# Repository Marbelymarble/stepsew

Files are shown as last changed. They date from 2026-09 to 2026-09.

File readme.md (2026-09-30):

# Stepsew

ESP32 firmware for a pedal-controlled sewing-machine stepper motor. Releasing
the pedal after sewing stops the needle at bottom dead center (BDC). Short
pedal taps at rest toggle the needle between BDC and top dead center (TDC).

## Build

```sh
pio run -e esp32dev
```

The project pins Espressif32 7.1.3 and FastAccelStepper 1.3.0. Position capture
uses the classic ESP32's IDF 4 pulse-counter hardware; changing to another ESP32
variant or an IDF 5 platform requires adapting that code. Compiler warnings in
project sources are treated as errors.

## Wiring and configuration

Settings live in [`include/config.h`](include/config.h).

| Signal | GPIO | Configuration |
| --- | --- | --- |
| Motor STEP | 14 | Rising-edge step pulses |
| Motor DIR | 27 | Fixed LOW; forward-only operation |
| Motor ENABLE | 26 | Active LOW |
| Pedal | 2 | 12-bit analog input |
| BDC sensor | 33 | Pull-up input; falling edge marks BDC |

The defaults retain 2,000 pulses per motor revolution, 60–3,000 motor RPM, and
400,000 steps/s² acceleration. Pedal thresholds remain 2,000 for starting and
2,250 for variable speed, with 20 counts of hysteresis. Readings are sampled
every millisecond and averaged over 20 samples. The speed curve uses exponent
1.2 and is clamped to the configured speed limits.

`kStepsPerNeedleCycle` is independent of `kMotorStepsPerRevolution`. The current
value of 4,667 accounts for approximately 2.33 motor revolutions per needle
cycle with 2,000 pulses per motor revolution. Confirm the exact ratio from
pulley tooth counts or the measured BDC crossing interval. This value includes
both the pulley ratio and motor-driver microstep setting.

Align the sensor's falling edge with physical BDC. `kBdcOffsetSteps` can add a
forward offset when the sensor is mounted before BDC. The final position must
remain within the sensor's active LOW region. Homing accepts one captured
sensor pulse to plan the approach; it does not require two crossings with
matching spacing. A fresh edge is then required during the final moving
search. Both homing and the return tap use that same search.

`kBdcToTdcSteps` sets the forward distance from BDC to TDC. Its default is half
a needle cycle (2,333 steps). The return move watches for the next BDC edge
throughout its forward travel from TDC. Both moves rotate
forward. Calibrate this distance if the machine's linkage
does not put TDC exactly half a cycle after BDC. There is no TDC sensor: its
position is inferred from the established BDC reference and counted STEP pulses.

## Short pedal taps

After a successful BDC stop:

- Press and release the pedal within 20–250 ms to raise the needle to TDC.
- Once the needle has stopped at TDC, another short tap lowers it to BDC.
- Hold the pedal for 250 ms to start normal sewing. Releasing it after sewing
  homes to BDC as usual.

The motor stays still while distinguishing a tap from a held press. Tap motion
starts on pedal release. The upward move runs at 60 RPM and takes about
1.2 seconds with the default settings. The downward move scans continuously
at 60 RPM from TDC and requests normal deceleration when a falling edge is
captured. It clears pending capture and the preceding debounce lockout before
starting, and uses speed-dependent debounce throughout the return. Capture is
not restricted to an estimated half-cycle endpoint or a narrow window around it.
The return has a finite travel limit of one nominal needle cycle (4,667 steps),
so a missing signal cannot cause unlimited rotation. It normally stops at the
first usable BDC crossing, about half a cycle from TDC. Homing also allows
a full-cycle search after its approach, so a noisy planning reference cannot
restrict final capture to a narrow predicted window.

Queued pulses and braking cause some travel beyond the captured edge. The
maximum accepted travel beyond the configured BDC offset is calculated from
speed, queue planning, latency allowance, and acceleration
(`kBdcCaptureToleranceSteps`: 44 pulses, about 3.4° of the needle cycle at
60 RPM). A direct scan entered from up to 120 RPM budgets up to 97 pulses
for the initial queued speed and deceleration. This is a limit, not a commanded offset or a guarantee of exact
physical BDC. After motion ends, HIGH samples reset LOW qualification but
allow up to 50 ms (`kBdcStopQualificationMs`) for the mechanism/input to settle
before rejecting the candidate. The sensor must still stay LOW for 10 ms at
rest, followed by final verification. If the sensor's active region is too narrow for braking,
the search continues within its remaining travel budget and otherwise faults.
Align the magnet/sensor and calibrate `kBdcOffsetSteps` for the physical stop.
`BDC stop: edge_to_stop=... offset=...` reports the measured pulse travel.
The next upward move subtracts the measured overrun from its step count to
retain the configured TDC target relative to the captured BDC reference.
Tap duration is measured using the filtered pedal reading
and the existing start/release hysteresis; pulses shorter than 20 ms are ignored.
Adjust `kPedalTapMinMs` and `kPedalTapMaxMs` to change these durations.

Wait for each toggle to finish before tapping again. Short presses during a
toggle are ignored rather than queued. A held press during a toggle resumes
sewing after the same 250 ms threshold, including when the toggle finishes
during that press. A continuous hold cannot trigger repeated toggles.

The controller verifies the final pulse counts and requires a stable LOW BDC
sensor at BDC, or a stable HIGH sensor at TDC, before releasing the motor.
The upward toggle deadline is about 3.3 seconds with the current configuration
and scales with the configured needle-cycle length. Returning to BDC allows
three additional seconds for the search (`kBdcSearchTimeoutMs`). Timeout
messages distinguish motion, sensor search, and final sensor verification.
Failures latch the same fault as
homing; they do not switch the remembered needle position.

Taps are enabled only after a verified BDC stop. At power-up, a pedal press
starts sewing immediately as before; sew and release once to establish the
reference. A detected sensor crossing or changed level while parked invalidates
the reference. After manually moving the handwheel, sew and release again
before using taps: the single BDC sensor cannot detect every manual movement,
particularly near TDC.

## Stop behavior

1. Pedal release starts homing once, from either sewing-speed mode.
2. At or below `kPositionFeedbackMaxRpm` (120 motor RPM by default), release
   converts the existing motion directly into a finite scan at 60 RPM, watching
   for the next Hall edge immediately. Actual, queued, and requested speed
   must all be within the threshold. It logs `Homing: direct low-speed BDC scan`.
   This path has no predicted approach point and requires no earlier reference
   or qualifying stitch. A recent edge still under the sensor can request an
   immediate stop. Travel remains limited to one nominal cycle, and normal
   braking and final LOW verification still apply. An edge already passed
   outside the usable stop region cannot be recovered by reversing.
3. Above the low-speed threshold, the motor changes to 120 RPM
   (4,000 STEP pulses/s). The controller waits
   until current and queued speeds are low enough for 50 ms before planning
   the stop. `kHomingRpm` controls this speed independently of sewing and taps.
4. BDC pulses are tracked during sewing and deceleration for diagnostics.
   Once speed has settled, pending capture and the previous reference are
   discarded. One fresh falling edge at homing speed establishes the reference
   for the approach; no reference from high-speed motion is reused.
5. The motor moves forward to a reachable approach position 93 steps before
   the estimated BDC edge, adding complete needle cycles when required by
   queued pulses and braking distance (`kBdcApproachLeadSteps`). The estimate is
   only an approach target; the final scan allows a full nominal cycle.
   At the current ratio, one needle cycle at homing speed takes about 1.17 s.
6. `Homing: locating the BDC sensor edge` starts the same bounded, continuous
   60 RPM search used by the return tap. A fresh edge with a stable LOW at rest is
   required. An earlier sewing pulse alone cannot establish the final stop.
7. After applying any BDC offset, the controller verifies both the library's
   position and the independent hardware pulse count and requires the sensor
   to remain LOW for 10 ms before releasing the motor outputs.

A pedal press lasting at least 50 ms (`kHomingResumePressMs`) cancels homing
and resumes sewing. Release hysteresis resets that timer; a brief pedal rebound
cannot cancel the stop. The next release either starts a direct low-speed scan
or reacquires a reference at settled speed. A new sewing
session from rest starts fresh reference acquisition, so references from before
a handwheel adjustment are not reused. The controller does not automatically
move or assume it is homed at power-up.

The sensor interrupt applies a speed-dependent falling-edge lockout:

`lockout_us = 1,000,000 × steps_per_needle_cycle / pulses_per_second × 50%`

`kSensorDebouncePercent` controls that fraction. At steady speed the defaults
are about 1,167 ms at 60 motor RPM, 583 ms at 120 RPM, and 23 ms at 3,000 RPM.
The rate uses the highest actual, queued, or requested pulse frequency, so
acceleration shortens the lockout promptly. An active lockout uses the smaller
of its original duration and the current duration: deceleration cannot extend
it and hide the next crossing. Rejected edges do not restart the timer.
Calculations run in the control loop; the ISR uses the published duration and
retains the first edge's timestamp and pulse count.

The moving lockout is bounded by `kSensorDebounceMinUs` (1 ms) and
`kSensorDebounceMaxUs` (2 s). At rest the setting is
`kSensorStoppedDebounceUs` (500 ms). The final BDC search uses the same
speed-dependent debounce as sewing: there is no search-specific 1 ms override.
Candidate rejection does not reset debounce, so repeated edges from the same
burst cannot repeatedly restart braking. A false first edge can still mask a
nearby genuine edge during its lockout; the finite travel and time limits
remain in effect.

This suppresses repeated edges but cannot distinguish an isolated noise spike
from a genuine Hall crossing. No minimum pulse width is required. The handler
does not reread the input level to decide whether an edge counts:
a pulse may already have ended when the interrupt or control loop runs. The
first pending edge's timestamp and hardware pulse count are retained until the
loop consumes them, so bounce cannot replace that reference. Subsequent edges
within three quarters of a needle cycle are ignored based on motor travel.
No exact two-pulse spacing check is used. The final scan searches up to one
nominal cycle from the approach and faults if no usable edge is found. Large raw interrupt counts can indicate
chatter or interference; software cannot establish physical BDC from a signal
that also stays active at unrelated positions.

PCNT unit 7 independently counts STEP pulses, including while the application
is busy. The sensor interrupt captures that count without resetting the
library's position. Unsigned position differences handle counter wraparound.
Units used internally by FastAccelStepper are left available to the library.

`kForwardPlanningMs` is 8 ms, configured only during motor initialization.
FastAccelStepper's task refills roughly every 4 ms; this retains two refill
cycles while reducing queued travel before a normal stop can take effect.
At 60 RPM, 8 ms corresponds to 16 pulses, versus 40 pulses with the former
20 ms setting. Task timing and deceleration add further travel, so this is
neither an exact stop distance nor a guarantee that the magnet remains in the
sensor's active region. Both sewing and positioning use this queue setting;
check smooth high-speed operation as well as the final stop after changing it.

The homing deadline covers two needle cycles at homing speed, maximum
deceleration, settling, a one-second margin, and three seconds for the final
edge search (about 6.6 seconds total with the current settings). Missing or unusable sensor
signals, failed motor commands, and position mismatches latch a fault. The
motor decelerates and its outputs are released once it stops. If a fault stop
has not completed within one second, pending pulses are aborted. Correct the
cause and reset the controller to resume; pressing the pedal cannot clear a
fault. Serial output at 115200 baud reports state transitions and fault causes.

Homing timeout messages identify the stage that failed. They also report the
sensor level, raw falling-edge interrupts, `debounced` edges rejected by the
time lockout, captured/stale/ignored edges,
accepted references, last observed interval, last accepted interval, and
hardware pulse count. The last observed interval may describe rejected bounce;
the accepted interval shows spacing between references used for planning. Counts
cover the current sewing session, including deceleration and reference
acquisition. `raw=0` means no falling-edge interrupts reached the handler;
`raw` can exceed `captured` due to debounce and when multiple admitted edges
arrive before the loop consumes the first one. The interval is diagnostic only, not an exact-spacing
requirement. The 16-bit hardware pulse count wraps every 65,536 steps, while
the library position continues counting; only their low 16 bits must match.
Diagnostics are printed after requesting a stop, so they do not delay capture.

A live `BDC pin=33 HIGH raw=... db=... read=... merged=... us=...` status line
is attempted once per second, including while stopped or faulted. It skips
printing if the serial transmit buffer lacks room. These counters start at boot:

- `raw`: all falling-edge interrupts, before debounce.
- `db`: interrupts rejected by the time lockout.
- `read`: captured events consumed by the control loop, before position filtering.
- `merged`: admitted interrupts coalesced while an earlier event was pending.
- `us`: currently configured lockout in microseconds; an existing lockout may
  be shorter because it began at a faster speed.

The HIGH/LOW value is an instantaneous reading and may miss a short pulse;
the raw counter retains evidence of its interrupt. Moving the magnet past the
sensor by hand while stopped can therefore check capture independently of motor
operation. Search faults also print `observed`, `stale`, `outside`, and
`returned_HIGH` counts. The latter identifies captured candidates rejected
because LOW did not persist at rest. `BDC rejected edges` additionally reports
minimum and maximum pulse travel from those edges to standstill, to help
distinguish signal glitches from braking past the active region. These counts
alone do not prove which cause applies. `outside` includes approach edges before
the final search window, which are normally ignored.

## Hardware verification

A successful build cannot establish mechanical positioning accuracy. Before
using the positioning feature:

- Confirm the driver microstep setting, pulses per needle cycle, rotation
  direction, and the sensor's falling-edge alignment with needle-down BDC.
- Release the pedal from minimum and higher speeds at several points in the
  needle cycle. Confirm the needle consistently finishes at BDC, motion has
  ended before ENABLE is released, and the serial output reaches `Stopped`.
- Press the pedal again while slowing, seeking BDC, and approaching the target.
  Confirm sewing resumes without reversing or briefly disabling the driver.
- After a verified BDC stop, tap once and check physical TDC, then tap again
  and check BDC. The return should report `Tap: locating the BDC sensor edge`
  before `Stopped: needle at BDC`. Confirm each tap produces just one toggle,
  all motion is forward, and the needle stays at its final position after the
  driver is released. Repeat the sequence to check that BDC does not drift.
- Hold the pedal at BDC and TDC. Confirm normal sewing starts after 250 ms and
  releasing the pedal returns to BDC. Check a held press during a toggle too.
- With the mechanism unloaded, check a disconnected sensor and a sensor held
  LOW. Homing must time out, stop the motor, and reject pedal input until reset.
- Check repeated stops and restarting after manually turning the handwheel.
  Release at different points during minimum-speed sewing and check for the
  direct-scan message, without `Homing: approaching BDC`. Release after fast sewing and check for fresh reference
  acquisition after speed settling. If BDC verification fails, check
  the sensor's active region and calibration rather than increasing the timeout.

No software tests are included.

## Source layout

- `main.cpp`: Arduino setup and control-loop scheduling.
- `machine.cpp`: sewing, tap gestures, BDC/TDC positioning, and fault states.
- `stepper.cpp`: FastAccelStepper commands and pulse-based stop planning.
- `bdc_sensor.cpp`: interrupt capture and atomic event transfer.
- `pedal.cpp`: fixed-size averaging and bounded speed mapping.

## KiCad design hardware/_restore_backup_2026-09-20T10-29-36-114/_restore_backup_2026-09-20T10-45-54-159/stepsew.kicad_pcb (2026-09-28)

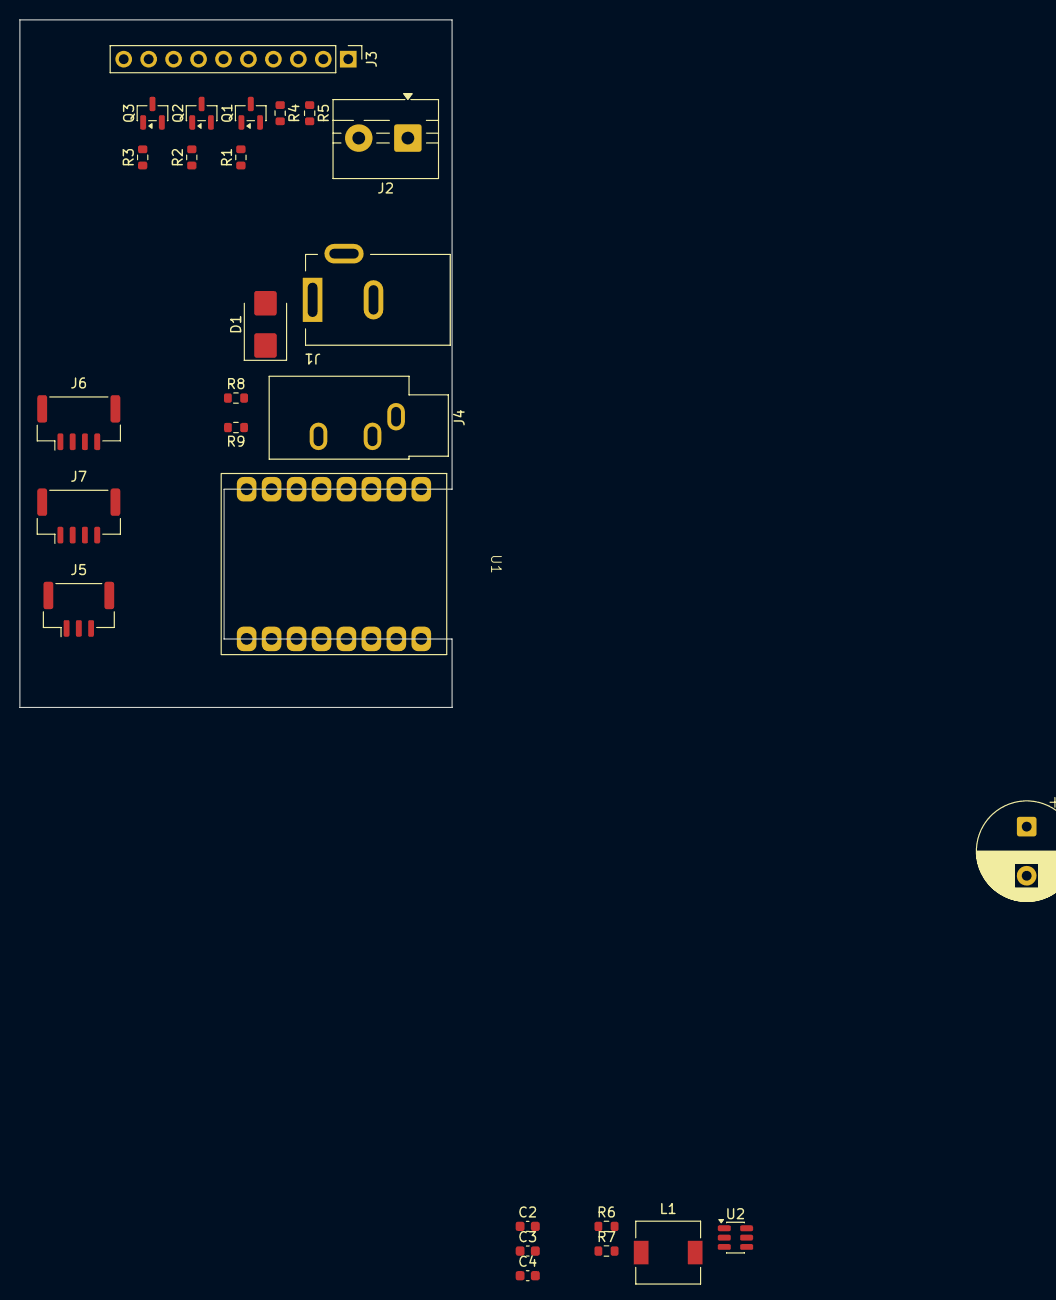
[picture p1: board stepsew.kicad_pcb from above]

Board: 2 copper layers, 44.0 x 70.0 mm, 27 parts (0 on the bottom side), 27 nets, no tracks yet.

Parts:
C1: 330uF 63V; CP_Radial_D10.0mm_P5.00mm
C2: 2u2; C_0603_1608Metric
C3: 100n; C_0603_1608Metric
C4: 10u; C_0603_1608Metric
D1: D_TVS; D_SMB
J1: Barrel_Jack_MountingPin; BarrelJack_Kycon_KLDX-0202-xC_Horizontal
J2: Servo Power; TerminalBlock_MaiXu_MX126-5.0-02P_1x02_P5.00mm
J3: Servo Header; PinHeader_1x10_P2.54mm_Vertical
J4: Pedal; Jack_3.5mm_CUI_SJ1-3533NG_Horizontal
J5: HallSensor; JST_GH_BM03B-GHS-TBT_1x03-1MP_P1.25mm_Vertical
J6: OLED; JST_GH_BM04B-GHS-TBT_1x04-1MP_P1.25mm_Vertical
J7: Encoder; JST_GH_BM04B-GHS-TBT_1x04-1MP_P1.25mm_Vertical
L1: 15uH; L_6.3x6.3_H3
Q1, Q2, Q3: BC817; SOT-23
R1, R2, R3: 220R; R_0603_1608Metric
R4, R5: 10k; R_0603_1608Metric
R6: 118k; R_0603_1608Metric
R7: 22k1; R_0603_1608Metric
R8: 1k; R_0603_1608Metric
R9: 6k8; R_0603_1608Metric
U1: ESP32-C3-SuperMini
U2: LMR54406; SOT-23-6

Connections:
+3V3: J6.1, R4.2, R5.2, R8.1
+5V: C4.1, J3.6, J3.8, J3.10, J5.1, L1.2, R6.1
+36V: C1.1, C2.1, D1.2 (A2), J1.1, J2.1, U2.4 (~SHDN), U2.5 (VIN)
/Enc_A: J7.1, U1.4 (GPIO4)
/Enc_B: J7.2, U1.3 (GPIO3)
/Enc_SW: J7.3, U1.2 (GPIO2)
/PEDAL: J4.S, R8.2, U1.0 (GPIO0)
/SCL: J6.3, U1.7 (GPIO7)
/SDA: J6.4, U1.6 (GPIO6)
/Sensor: J5.2, U1.1 (GPIO1)
/~ALM: J3.1, R3.1, U1.10 (GPIO10), U1.20 (GPIO20)
/~DIR: R2.1, U1.9 (GPIO9)
/~ENA: R1.1, U1.8 (GPIO8)
/~PED: J3.3, U1.21 (GPIO21)
GND: C1.2, C2.2, C4.2, D1.1 (A1), J1.2, J2.2, J5.3, J6.2, J7.4, Q1.2 (E), Q2.2 (E), Q3.2 (E), R7.2, R9.2, U2.2 (GND)
unnamed: J3.2, R5.1
unnamed: J3.4, R4.1
unnamed: J3.5, Q1.3 (C)
unnamed: J3.7, Q2.3 (C)
unnamed: J3.9, Q3.3 (C)
unnamed: J4.T, R9.1
unnamed: Q1.1 (B), R1.2
unnamed: Q2.1 (B), R2.2
unnamed: Q3.1 (B), R3.2
unnamed: C3.1, U2.1 (CB)
unnamed: R6.2, R7.1, U2.3 (FB)
unnamed: C3.2, L1.1, U2.6 (SW)

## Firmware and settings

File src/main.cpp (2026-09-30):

#include <Arduino.h>

#include "config.h"
#include "bdc_sensor.h"
#include "machine.h"
#include "pedal.h"

namespace {

uint32_t lastSampleMs = 0;

}  // namespace

void setup() {
  Serial.begin(Config::kSerialBaud);
  Pedal::begin();
  Machine::begin();
  lastSampleMs = millis() - Config::kControlPeriodMs;
}

void loop() {
  const uint32_t now = millis();
  if (static_cast<uint32_t>(now - lastSampleMs) < Config::kControlPeriodMs) {
    return;
  }
  // Do not insert back-to-back samples to catch up after a delayed iteration.
  lastSampleMs = now;
  Machine::update(Pedal::sample(), now);
  BdcSensor::reportDiagnostics(now);
}

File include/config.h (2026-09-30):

#pragma once

#include <stddef.h>
#include <stdint.h>

namespace Config {

constexpr uint8_t kStepPin = 14;
constexpr uint8_t kDirectionPin = 27;
constexpr uint8_t kEnablePin = 26;  // Active low.
constexpr uint8_t kPedalPin = 2;
constexpr uint8_t kBdcPin = 33;  // Active low; falling edge marks BDC.

constexpr uint32_t kSerialBaud = 115200;
constexpr uint32_t kControlPeriodMs = 1;
constexpr size_t kPedalSamples = 20;
constexpr int kPedalEnableThreshold = 2000;
constexpr int kPedalHysteresis = 20;
constexpr int kPedalVariableThreshold = 2250;
constexpr int kPedalMax = 4095;
constexpr float kPedalExponent = 1.2f;
constexpr uint32_t kPedalTapMinMs = 20;
constexpr uint32_t kPedalTapMaxMs = 250;
// Reject brief pedal rebound while homing, without imposing the tap hold delay.
constexpr uint32_t kHomingResumePressMs = 50;

constexpr uint32_t kMotorStepsPerRevolution = 2000;
// Approximately 2.33 motor revolutions per needle cycle (about 7:3).
// Confirm this rounded value against the sensor's measured crossing interval.
constexpr uint32_t kStepsPerNeedleCycle = 4667;
// Forward distance from physical BDC to TDC; adjust for the machine's linkage.
constexpr uint32_t kBdcToTdcSteps = kStepsPerNeedleCycle / 2;
// Calibrate the sensor's falling edge at BDC. A positive offset stops this many
// steps beyond that edge and must remain inside the sensor's active region.
constexpr uint32_t kBdcOffsetSteps = 0;
// Approach the expected BDC edge early, then scan at the needle-toggle speed.
// Stop 2% of a nominal cycle early; the final scan can cover a full cycle.
constexpr uint32_t kBdcApproachLeadSteps = kStepsPerNeedleCycle / 50;
constexpr uint32_t kBdcSearchTimeoutMs = 3000;
constexpr uint32_t kMinRpm = 60;
constexpr uint32_t kMaxRpm = 3000;
constexpr int32_t kAccelerationStepsPerSecondSquared = 400000;
constexpr uint32_t kHomingRpm = 150;
// At/below this actual, queued, and requested rate, scan directly on release.
constexpr uint32_t kPositionFeedbackMaxRpm = 150;
constexpr uint32_t kPositionFeedbackMaxHz =
    kPositionFeedbackMaxRpm * kMotorStepsPerRevolution / 60;
constexpr uint32_t kHomingHz = kHomingRpm * kMotorStepsPerRevolution / 60;
constexpr uint32_t kNeedleMoveHz = kMinRpm * kMotorStepsPerRevolution / 60;
// Allow a full needle cycle plus time for acceleration and final verification.
constexpr uint32_t kNeedleMoveTimeoutMs =
    1000 + (UINT64_C(1000) * kStepsPerNeedleCycle + kNeedleMoveHz - 1) / kNeedleMoveHz;

// PCNT 6 and 7 are free on the classic ESP32 with FastAccelStepper's IDF 4 driver.
constexpr uint8_t kPositionCounterUnit = 7;
constexpr uint32_t kSensorEventMaxAgeUs = 50000;
// Edge lockout, not a minimum LOW duration: short Hall pulses still count.
constexpr uint32_t kSensorDebouncePercent = 50;
constexpr uint32_t kSensorDebounceMinUs = 1000;
constexpr uint32_t kSensorDebounceMaxUs = 2000000;
constexpr uint32_t kSensorStoppedDebounceUs = 500000;
// Reject additional crossings within the same revolution, without demanding
// an exact interval from an approximate pulley ratio.
constexpr uint32_t kSensorMinSeparationSteps = kStepsPerNeedleCycle * 3 / 4;
constexpr uint32_t kReferenceMaxTravelSteps = kStepsPerNeedleCycle * 5 / 4;
constexpr uint32_t kHomingSpeedSettleMs = 50;
constexpr uint32_t kStopSettleMs = 10;
// Give the mechanism/input time to settle after STEP pulses end. During this
// window HIGH resets LOW qualification instead of immediately rejecting BDC.
constexpr uint32_t kBdcStopQualificationMs = 50;
constexpr uint32_t kFaultStopTimeoutMs = 1000;
// FastAccelStepper refills about every 4 ms. Two cycles of lookahead reduce
// sensor-to-stop latency while retaining a refill margin. Set only at startup.
constexpr uint32_t kForwardPlanningMs = 8;
// Bound capture-to-stop travel: queued motion, control/engine latency, braking.
// The final Hall LOW check remains mandatory even within this pulse budget.
constexpr uint32_t bdcCaptureToleranceSteps(uint32_t speedHz) {
  return (speedHz * (kForwardPlanningMs + kControlPeriodMs + 10) + 999) / 1000 +
         (UINT64_C(1) * speedHz * speedHz + 2 * kAccelerationStepsPerSecondSquared - 1) /
             (2 * kAccelerationStepsPerSecondSquared) + 1;
}
constexpr uint32_t kBdcCaptureToleranceSteps = bdcCaptureToleranceSteps(kNeedleMoveHz);
constexpr uint32_t kPlanningMarginSteps = kHomingHz / 20;  // 50 ms at homing speed.
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

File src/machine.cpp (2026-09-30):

#include "machine.h"

#include <Arduino.h>

#include "bdc_sensor.h"
#include "config.h"
#include "pedal.h"
#include "stepper.h"

namespace {

enum class State {
  Stopped,
  MinimumSpeed,
  VariableSpeed,
  Slowing,
  SeekingBdc,
  Positioning,
  HomingBdcSearch,
  HomingBdcOffset,
  Settling,
  MovingNeedle,
  SeekingNeedleBdc,
  SettlingNeedle,
  Fault
};

enum class NeedlePosition { Unknown, Bottom, Top };

State state = State::Stopped;
NeedlePosition needlePosition = NeedlePosition::Unknown;
NeedlePosition needleDestination = NeedlePosition::Unknown;
uint32_t homingStartedMs = 0;
uint32_t slowSinceMs = 0;
uint32_t settledSinceMs = 0;
uint32_t faultStartedMs = 0;
uint32_t referencePosition = 0;
uint32_t targetPosition = 0;
uint32_t needleMoveStartedMs = 0;
uint32_t bdcParkOverrunSteps = 0;
uint32_t bdcSearchStart = 0;
uint32_t bdcSearchRemaining = 0;
uint32_t bdcSearchLimit = 0;
uint32_t bdcEdgePosition = 0;
uint32_t bdcCaptureTolerance = Config::kBdcCaptureToleranceSteps;
bool bdcAcceptEntryEdge = false;
bool bdcSearchStarted = false;
bool bdcSearchStopping = false;
bool bdcStopObserved = false;
uint32_t bdcStoppedSinceMs = 0;
bool haveBdcEdge = false;
bool bdcCandidateLow = false;
uint32_t bdcCandidateLowSinceMs = 0;
uint32_t pedalPressedMs = 0;
bool slowSpeedReached = false;
bool haveReference = false;
bool sensorSettled = false;
bool pedalDown = false;
bool tapEligible = false;
bool delayStartForTap = false;

struct ReferenceDiagnostics {
  uint32_t rawEdgeStart = 0;
  uint32_t debounceRejectedStart = 0;
  uint32_t edges = 0;
  uint32_t staleEdges = 0;
  uint32_t ignoredEdges = 0;
  uint32_t acceptedEdges = 0;
  uint32_t lastIntervalSteps = 0;
  uint32_t lastAcceptedIntervalSteps = 0;
};

ReferenceDiagnostics referenceDiagnostics;

struct SearchDiagnostics {
  uint32_t observed = 0;
  uint32_t stale = 0;
  uint32_t outsideWindow = 0;
  uint32_t returnedHigh = 0;
  uint32_t minRejectedTravel = UINT32_MAX;
  uint32_t maxRejectedTravel = 0;
};

SearchDiagnostics searchDiagnostics;

const char* stateName(State value) {
  switch (value) {
    case State::Stopped:
      if (needlePosition == NeedlePosition::Bottom) {
        return "Stopped: needle at BDC";
      }
      if (needlePosition == NeedlePosition::Top) {
        return "Stopped: needle at TDC";
      }
      return "Stopped";
    case State::MinimumSpeed: return "Sewing: minimum speed";
    case State::VariableSpeed: return "Sewing: pedal speed";
    case State::Slowing: return "Homing: settling at homing speed";
    case State::SeekingBdc: return "Homing: acquiring BDC reference";
    case State::Positioning: return "Homing: approaching BDC";
    case State::HomingBdcSearch: return "Homing: locating the BDC sensor edge";
    case State::HomingBdcOffset: return "Homing: applying BDC offset";
    case State::Settling: return "Homing: checking final position";
    case State::MovingNeedle: return "Tap: moving needle to the opposite position";
    case State::SeekingNeedleBdc: return "Tap: locating the BDC sensor edge";
    case State::SettlingNeedle: return "Tap: checking final position";
    case State::Fault: return "FAULT: reset controller to resume";
  }
  return "Unknown state";
}

void changeState(State next) {
  if (state != next) {
    state = next;
    Serial.println(stateName(state));
  }
}

void fault(const char* reason, uint32_t nowMs) {
  const bool wasSearching = state == State::HomingBdcSearch || state == State::SeekingNeedleBdc;
  needlePosition = NeedlePosition::Unknown;
  tapEligible = false;
  haveReference = false;
  Motor::requestStop();
  faultStartedMs = nowMs;
  changeState(State::Fault);
  Serial.println(reason);
  if (wasSearching) {
    Serial.printf("BDC search edges: observed=%lu stale=%lu outside=%lu returned_HIGH=%lu latched=%s\n",
                  static_cast<unsigned long>(searchDiagnostics.observed),
                  static_cast<unsigned long>(searchDiagnostics.stale),
                  static_cast<unsigned long>(searchDiagnostics.outsideWindow),
                  static_cast<unsigned long>(searchDiagnostics.returnedHigh),
                  haveBdcEdge ? "yes" : "no");
    if (searchDiagnostics.returnedHigh > 0) {
      Serial.printf("BDC rejected edges: edge_to_stop_min=%lu edge_to_stop_max=%lu allowed=%lu\n",
                    static_cast<unsigned long>(searchDiagnostics.minRejectedTravel),
                    static_cast<unsigned long>(searchDiagnostics.maxRejectedTravel),
                    static_cast<unsigned long>(bdcCaptureTolerance));
    }
  }
}

bool isHoming() {
  return state == State::Slowing || state == State::SeekingBdc ||
         state == State::Positioning || state == State::HomingBdcSearch ||
         state == State::HomingBdcOffset || state == State::Settling;
}

bool isMovingNeedle() {
  return state == State::MovingNeedle || state == State::SeekingNeedleBdc ||
         state == State::SettlingNeedle;
}

void updateSensorDebounce() {
  const uint32_t speedHz = Motor::debounceSpeedHz();
  uint32_t intervalUs = Config::kSensorStoppedDebounceUs;
  if (speedHz > 0) {
    const uint64_t cycleFractionUs = UINT64_C(1000000) * Config::kStepsPerNeedleCycle *
                                     Config::kSensorDebouncePercent / (UINT64_C(100) * speedHz);
    intervalUs = cycleFractionUs > Config::kSensorDebounceMaxUs
                     ? Config::kSensorDebounceMaxUs : static_cast<uint32_t>(cycleFractionUs);
    if (intervalUs < Config::kSensorDebounceMinUs) {
      intervalUs = Config::kSensorDebounceMinUs;
    }
  }
  BdcSensor::setDebounceUs(intervalUs);
}

bool sensorMatches(NeedlePosition position) {
  return position != NeedlePosition::Unknown &&
         BdcSensor::isActive() == (position == NeedlePosition::Bottom);
}

bool updatePedalGesture(bool pressed, bool released, uint32_t nowMs) {
  if (!pedalDown && pressed) {
    pedalDown = true;
    pedalPressedMs = nowMs;
    tapEligible = state == State::Stopped && needlePosition != NeedlePosition::Unknown;
    delayStartForTap = tapEligible || isMovingNeedle();
  }
  if (pedalDown && released) {
    pedalDown = false;
    const uint32_t duration = nowMs - pedalPressedMs;
    const bool tapped = tapEligible && duration >= Config::kPedalTapMinMs &&
                        duration <= Config::kPedalTapMaxMs;
    tapEligible = false;
    return tapped;
  }
  return false;
}
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

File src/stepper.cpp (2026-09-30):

#include "stepper.h"

#include <Arduino.h>
#include <FastAccelStepper.h>

#include "config.h"

#if !CONFIG_IDF_TARGET_ESP32 || ESP_IDF_VERSION_MAJOR != 4
#error "Position capture requires the classic ESP32 and the pinned Arduino/IDF 4 platform"
#endif

namespace {

FastAccelStepperEngine engine;
FastAccelStepper* stepper = nullptr;
uint32_t commandedRpm = 0;
uint32_t commandedHz = Config::kHomingHz;

int64_t forwardDistance(uint32_t from, uint32_t to) {
  const uint32_t difference = to - from;
  return difference <= INT32_MAX ? static_cast<int64_t>(difference)
                                 : static_cast<int64_t>(difference) - (INT64_C(1) << 32);
}

}  // namespace

namespace Motor {

bool begin() {
  digitalWrite(Config::kEnablePin, HIGH);
  pinMode(Config::kEnablePin, OUTPUT);
  digitalWrite(Config::kDirectionPin, LOW);
  pinMode(Config::kDirectionPin, OUTPUT);

  engine.init();
  stepper = engine.stepperConnectToPin(Config::kStepPin);
  if (stepper == nullptr) {
    return false;
  }
  // Keep the physical direction LOW, as in the original wiring. Omitting a
  // direction pin from the library also prevents accidental reverse moves.
  stepper->setEnablePin(Config::kEnablePin, true);
  stepper->setAutoEnable(false);
  stepper->setForwardPlanningTimeInMs(Config::kForwardPlanningMs);
  return stepper->disableOutputs() &&
         stepper->setAcceleration(Config::kAccelerationStepsPerSecondSquared) == 0 &&
         stepper->setSpeedInHz(Config::kHomingHz) == 0 &&
         stepper->attachToPulseCounter(Config::kPositionCounterUnit, 0, 0);
}

bool run(uint32_t rpm) {
  if (stepper == nullptr || rpm < Config::kMinRpm || rpm > Config::kMaxRpm) {
    return false;
  }
  if (rpm == commandedRpm && stepper->isRunningContinuously()) {
    return true;
  }
  const uint32_t frequency = rpm * Config::kMotorStepsPerRevolution / 60;
  if (stepper->setSpeedInHz(frequency) != 0 || !stepper->enableOutputs() ||
      stepper->runForward() != MOVE_OK) {
    return false;
  }
  commandedHz = frequency;
  commandedRpm = rpm;
  return true;
}

bool isRunning() {
  return stepper != nullptr && stepper->isRunning();
}

bool isAtHomingSpeed() {
  if (!isRunning()) {
    return false;
  }
  const int32_t actualSpeed = stepper->getCurrentSpeedInMilliHz();
  const int32_t plannedSpeed = stepper->getCurrentSpeedInMilliHz(false);
  const int32_t limit = Config::kHomingHz * 1000;
  return actualSpeed > 0 && actualSpeed <= limit && plannedSpeed > 0 && plannedSpeed <= limit;
}

uint32_t debounceSpeedHz() {
  if (!isRunning()) {
    return 0;
  }
  const int32_t actual = stepper->getCurrentSpeedInMilliHz();
  const int32_t planned = stepper->getCurrentSpeedInMilliHz(false);
  const int32_t fastest = actual > planned ? actual : planned;
  const uint32_t measuredHz = fastest > 0 ? (static_cast<uint32_t>(fastest) + 999) / 1000 : 0;
  // Include the requested rate so acceleration cannot leave a slow-speed
  // lockout in effect when the next crossing arrives sooner.
  return measuredHz > commandedHz ? measuredHz : commandedHz;
}

void requestStop() {
  commandedRpm = 0;
  if (stepper != nullptr) {
    stepper->stopMove();
  }
}

void abort() {
  // Only used for a latched fault if normal deceleration fails to finish.
  // The position becomes invalid and a controller reset is required.
  if (stepper != nullptr) {
    stepper->forceStopAndNewPosition(0);
  }
}

bool release() {
  if (stepper == nullptr) {
    digitalWrite(Config::kEnablePin, HIGH);
    return true;
  }
  return !stepper->isRunning() && stepper->disableOutputs();
}

uint32_t position() {
  return stepper == nullptr ? 0 : static_cast<uint32_t>(stepper->getCurrentPosition());
}

uint16_t pulseCount() {
  return stepper == nullptr ? 0 : static_cast<uint16_t>(stepper->readPulseCounter());
}

uint32_t positionAtPulseCount(uint16_t pulseCount) {
  // The free-running PCNT and the stepper share an initial zero and are never
  // rebased while moving. Reconstruct the edge's 32-bit position from its low
  // 16 bits. Only fresh edges within kSensorEventMaxAgeUs may be passed here.
  const uint32_t nearbyPosition = position();
  const uint16_t difference = pulseCount - static_cast<uint16_t>(nearbyPosition);
  const int32_t offset = difference <= INT16_MAX ? static_cast<int32_t>(difference)
                                                : static_cast<int32_t>(difference) - 65536;
  return nearbyPosition + static_cast<uint32_t>(offset);
}

bool moveToBdcApproach(uint32_t reference, uint32_t& target) {
  if (!isAtHomingSpeed()) {
    return false;
  }
  // Stop before the estimated edge; the machine controller finds actual BDC.
  target = reference - Config::kBdcApproachLeadSteps;
  const uint32_t queuedPosition = stepper->getPositionAfterCommandsCompleted();
  const int64_t lead = forwardDistance(queuedPosition, target);
  const int64_t requiredLead = stepper->stepsToStop() + Config::kPlanningMarginSteps;
  if (lead <= requiredLead) {
    const uint32_t extraCycles = static_cast<uint32_t>(
        (requiredLead - lead) / Config::kStepsPerNeedleCycle + 1);
    target += extraCycles * Config::kStepsPerNeedleCycle;
  }
  commandedRpm = 0;
  return stepper->moveTo(static_cast<int32_t>(target)) == MOVE_OK;
}

bool isAtTarget(uint32_t target) {
  return stepper != nullptr && !stepper->isRunning() && position() == target &&
         static_cast<uint16_t>(stepper->readPulseCounter()) == static_cast<uint16_t>(target);
}

bool scanForward(uint32_t steps, uint32_t& start, uint32_t& target) {
  if (!isAtHomingSpeed() || debounceSpeedHz() > Config::kPositionFeedbackMaxHz ||
      steps == 0 || steps > INT32_MAX) {
    return false;
  }
  start = position();
  target = start + steps;
  const uint32_t queuedPosition = stepper->getPositionAfterCommandsCompleted();
  if (forwardDistance(queuedPosition, target) <= stepper->stepsToStop()) {
    return false;
  }
  commandedRpm = 0;
  commandedHz = Config::kNeedleMoveHz;
  return stepper->setSpeedInHz(Config::kNeedleMoveHz) == 0 &&
         stepper->moveTo(static_cast<int32_t>(target)) == MOVE_OK;
}

bool moveForward(uint32_t steps, uint32_t& target) {
  if (stepper == nullptr || steps == 0 || steps > INT32_MAX || !isAtTarget(position())) {
    return false;
  }
  target = position() + steps;
  commandedRpm = 0;
  commandedHz = Config::kNeedleMoveHz;
  return stepper->setSpeedInHz(Config::kNeedleMoveHz) == 0 && stepper->enableOutputs() &&
         stepper->moveTo(static_cast<int32_t>(target)) == MOVE_OK;
}

}  // namespace Motor
